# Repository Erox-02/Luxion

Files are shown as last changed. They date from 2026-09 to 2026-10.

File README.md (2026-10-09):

# Luxion

Luxion is a custom made drone made with rust unlike standard c++ drones .
It uses a custom pcb, ESP32-S3-WROOM-1U , MPU6500-IMU(breakout as it costs less than the bare), four motor drivers, and a 1S LiPo to power the drone. Also a remote with
same esp module, 2x joysticks connectin to the drone via esp-now .

## Function

It is a remote controlled drone made from absolutely nothing , with 8520 motors and 65mm props it can easily take off with 2+ thrust-mass ratio . It is ideal for mini quadcoptor with mountable sensors ,as it has a lot of gpio's left any sensor can be easily mounted if not too heavy .

## Why it exists

from when i saw the pluto x  , a programable drone with esp 12f and stm32 , i always wanted to make one myself but better and cheaper thts why luxion exists today. I used esp32-s3 instead of 2 mcu's , used esp-now instead of wifi and a lot but the best part i didnt rely on the pluto x's architecture at all .

## Design
---

### 3D Model

> **Notice: All the screws there are 3mm .** 

The recommended range by me is M5x3 mm 

heres a photo tagged:
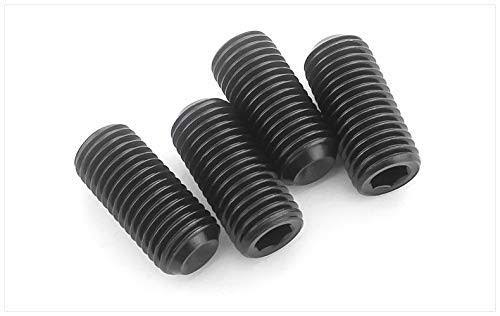
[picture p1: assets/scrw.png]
 

but for the pcb M1.2x3 mm is totally usable 

#### Drone

You can download the 3d model frm here :
[DOWNLOAD THE 3d MODEL](3d/lux.3mf)

also the  fcstd file is tagged here :

[FCSTD](3d/lux.FCStd)

some photos for the frame :

<table>
  <tr>
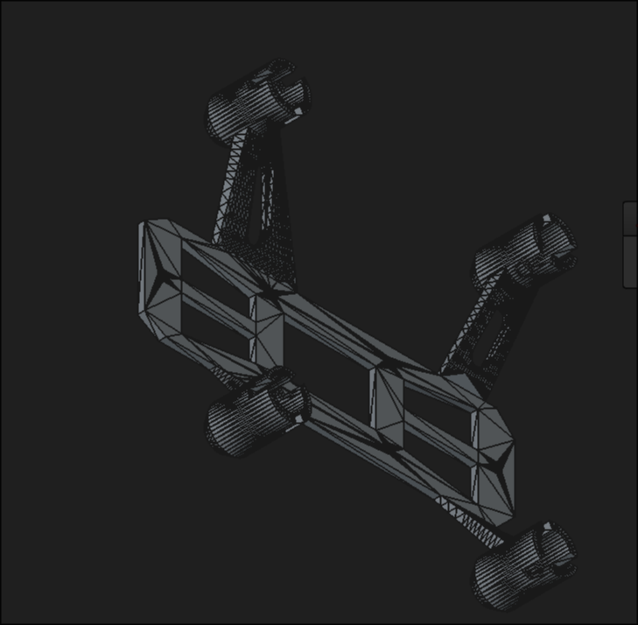
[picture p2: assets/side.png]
side view
    <td></td>
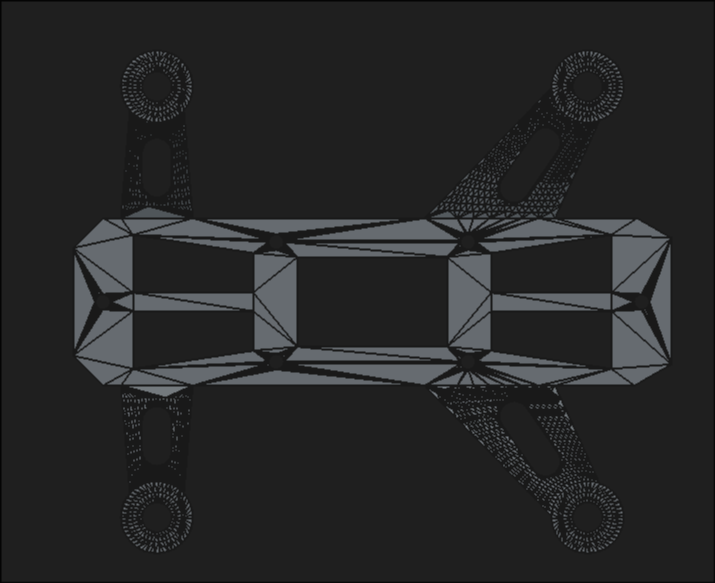
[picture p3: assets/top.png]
top view
    <td></td>
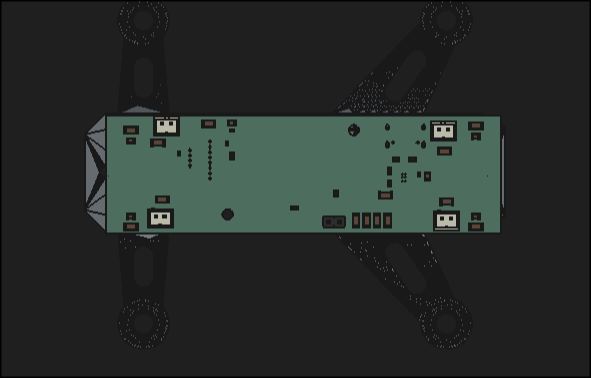
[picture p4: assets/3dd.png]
with pcb
    <td></td>
  </tr>
</table>

---

#### Remote

You can download the 3d model frm here :

[DOWNLOAD THE 3d MODEL](3d/remote-body.3mf)
[DOWNLOAD THE 3d MODEL](3d/remote-lid.3mf)

===

also the  fcstd file is tagged here :

[FCSTD](3d/remote.FCStd)

Some phots of the remote :

<table>
  <tr>
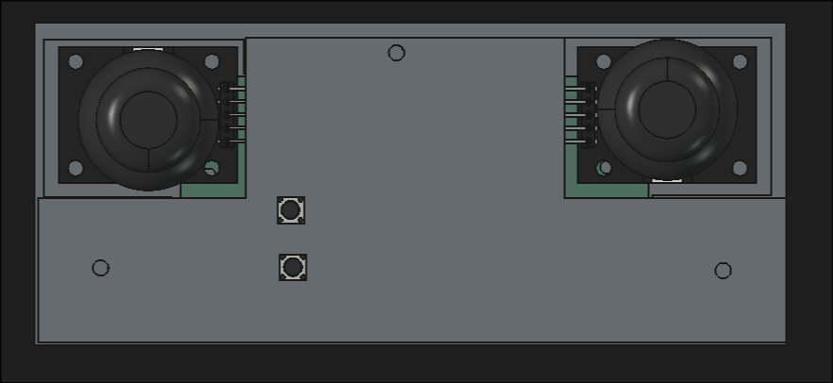
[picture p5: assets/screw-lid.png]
top
    <td></td>
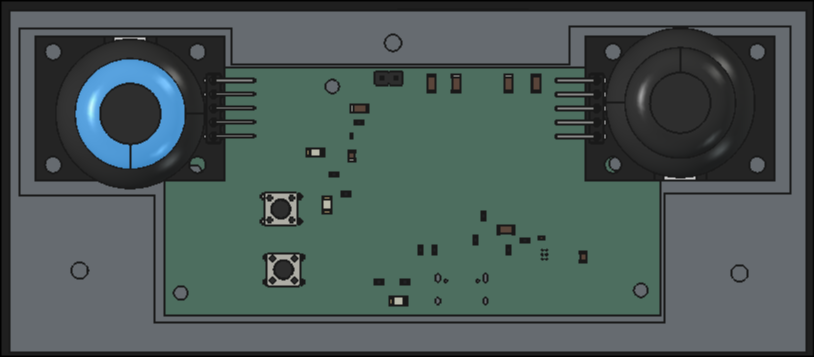
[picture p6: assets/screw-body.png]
case open
    <td></td>
  </tr>
</table>

---

### Schematic
---

#### drone

<table>
  <tr>
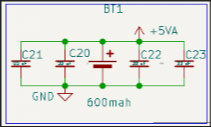
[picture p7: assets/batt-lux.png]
battery
    <td></td>
    <td>motor drivers</td>
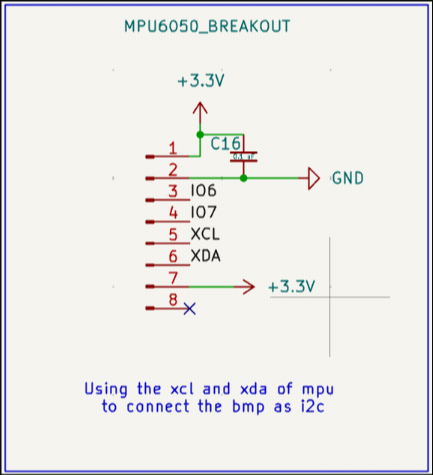
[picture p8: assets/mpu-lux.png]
mpu6050
    <td></td>
  </tr>
  <tr>
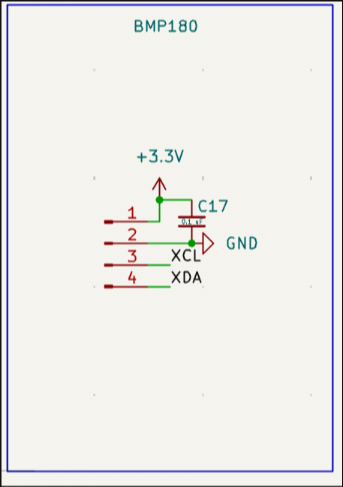
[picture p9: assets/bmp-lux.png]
barometer
    <td></td>
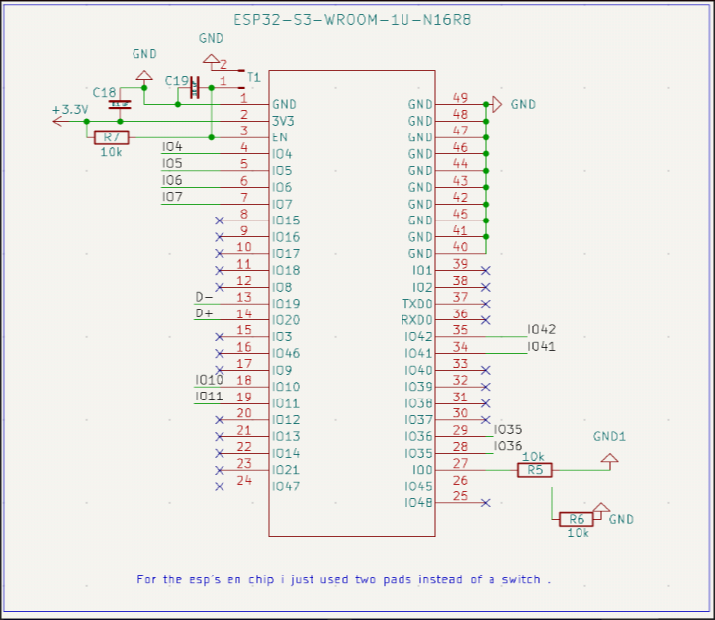
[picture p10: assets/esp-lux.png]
mcu(esp32-s3)
    <td></td>
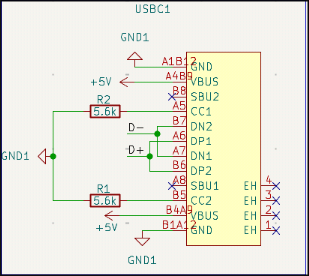
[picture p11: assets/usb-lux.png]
usb-c
    <td></td>
  </tr>
  <tr>
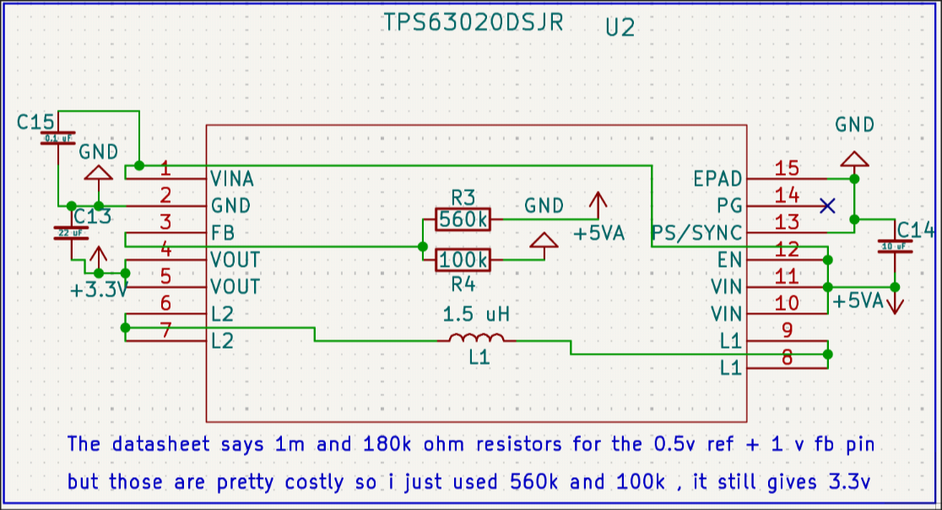
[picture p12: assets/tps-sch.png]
step up (tps63020)
    <td></td>
    <td>motors</td>
  </tr>
</table>

---

#### remote
---

<table>
  <tr>
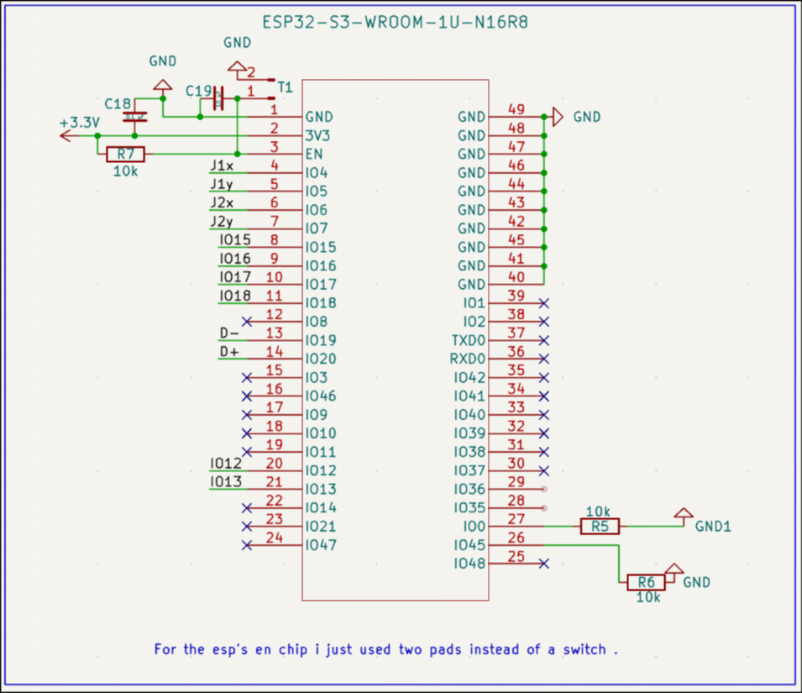
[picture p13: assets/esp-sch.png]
mcu
    <td></td>
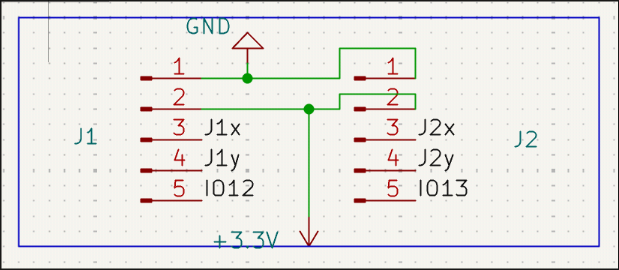
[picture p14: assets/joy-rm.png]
joystick
    <td></td>
  </tr>
  <tr>
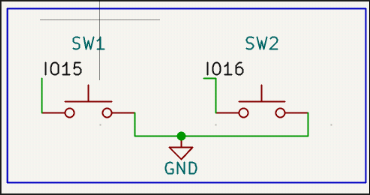
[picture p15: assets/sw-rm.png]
switchs
    <td></td>
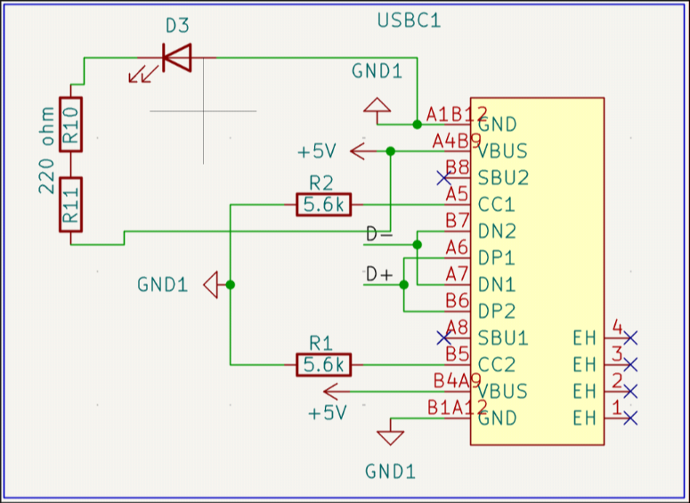
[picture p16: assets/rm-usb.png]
usb c
    <td></td>
  </tr>
</table>

### PCB

#### drone

Heres the pcb :

<table>
  <tr>
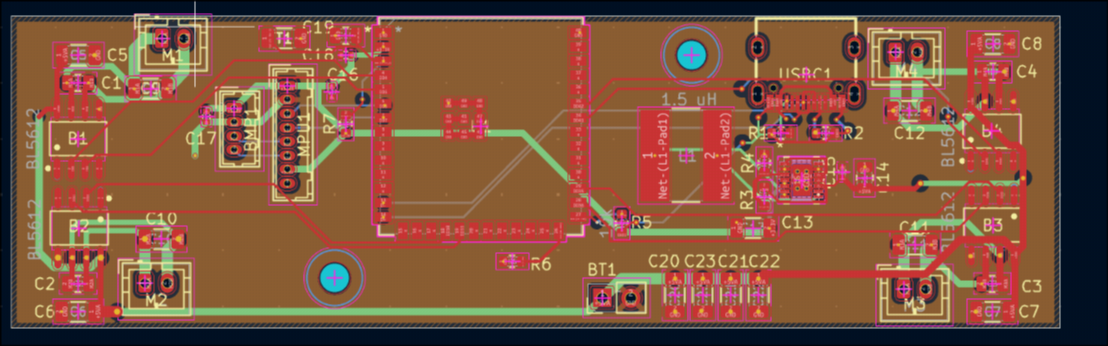
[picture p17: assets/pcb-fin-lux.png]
drone pcb
    <td></td>
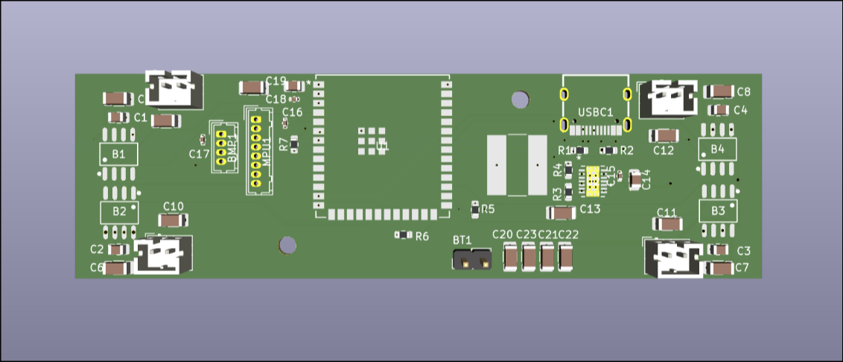
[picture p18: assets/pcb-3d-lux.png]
drone pcb 3d
    <td></td>
  </tr>
</table>

#### remote

Heres the pcb :

<table>
  <tr>
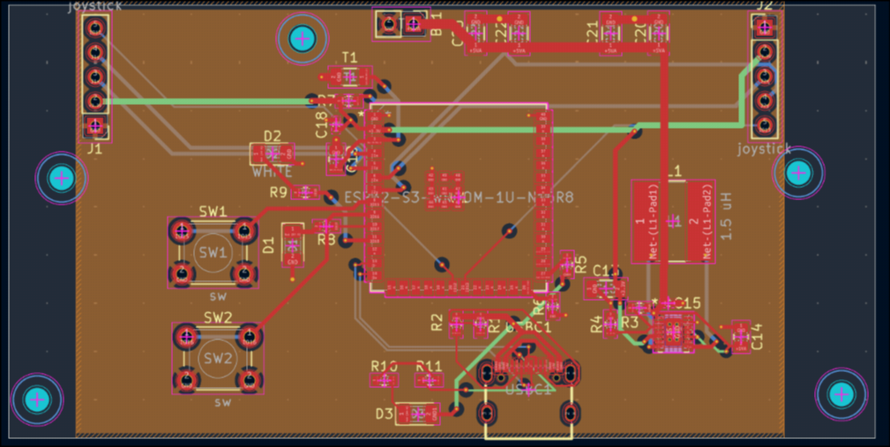
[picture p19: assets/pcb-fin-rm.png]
remote pcb
    <td></td>
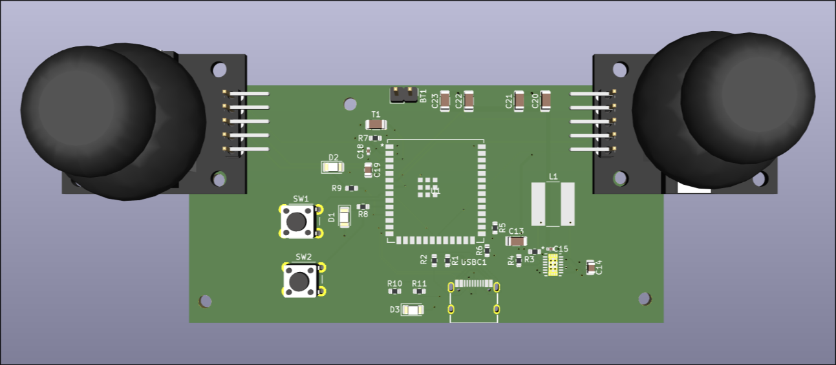
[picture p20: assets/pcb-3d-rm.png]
remote pcb 3d
    <td></td>
  </tr>
</table>

## Firmware

I have written likely most of the firmware already before getting approved or building the physical drone .

Current stack have :
```
[erox@archbtw luxion]$ tree src 
src
├── filter.rs
├── main.rs
├── motor.rs
├── mpu.rs          
└── pid.rs

1 directory, 5 files
```

the mpu.rs is a custom driver(really basic) for the mpu6050 , the filte* take mpu's data(gyro and acc) then converts tht into yaw roll and pitch , the moto* haved ldec and controlls the motors state , the pid is just pid controller nothing more , and the main.rs integrates them all and runs them when needed either in loop or once .

### Whats remainin?

- esp now impl
- build.rs
- proper pid vals and calibration

## How to assemble

Solder all the components from bom(except the antenna) on the pcb ,
also You might need to solder a jst socket according to your battery
(more detailed explanation after i do it myself first lol)

you can follow this hand drawn diagram(even orphy is better than me)
---
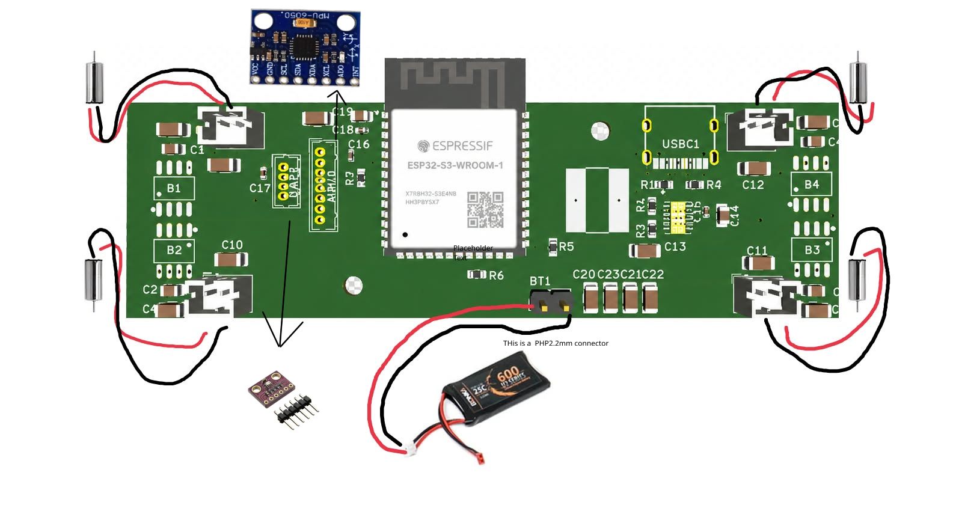
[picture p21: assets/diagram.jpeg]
diagram

---

## Credits

This project uses:

- KiCad
- Freecad for 3D renders
- A opensource frame from the link below

[link](https://www.thingiverse.com/thing:5013951)

> It was the reference for my frame i had to rebuild it .

## JLCPCB order

---
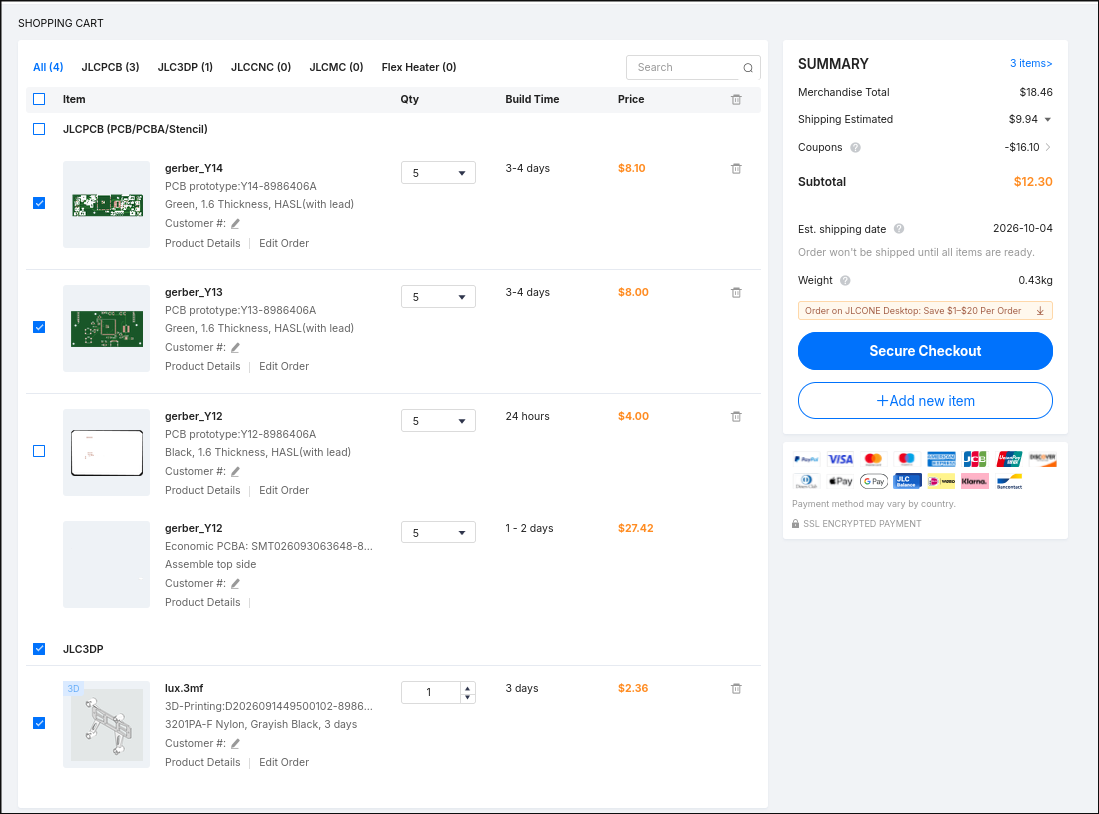
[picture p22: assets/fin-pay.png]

---

> the price might fluctuate over time

## BOM

| Part | Quantity | Unit Price (INR) | Unit Price (USD) | Total (INR) | Total (USD) | Link |
|---|---:|---:|---:|---:|---:|---|
| MPU-6050 3-Axis Accelerometer + Gyro | 1 | 151.00 | 1.59 | 151.00 | 1.59 | [Link](https://robu.in/product/mpu-6050-gyro-sensor-2-accelerometer/) |
| PS2 Joystick Module Breakout Sensor | 2 | 39.00 | 0.41 | 78.00 | 0.82 | [Link](https://robu.in/product/joystick-module-ps2-breakout-sensor/) |
| 8520 Magnetic Micro Coreless Motors – 2xCW + 2xCCW pack | 1 | 459.00 | 4.83 | 459.00 | 4.83 | [Link](https://robu.in/product/8520-magnetic-micro-coreless-motor-for-micro-quadcopters-2xcw-2xccw/) |
| 100kΩ 0603 resistor (MOQ) | 30 | 0.34 | 0.004 | 10.20 | 0.11 | [Link](https://robu.in/product/100k-ohm-1-4w-0603-surface-mount-chip-resistor-pack-of-100/) |
| 220Ω 0603 resistor (MOQ) | 30 | 0.34 | 0.004 | 10.20 | 0.11 | [Link](https://robu.in/product/220-ohm-chip-resistor-1-4w-0603-surface-mount-pack-of-100/) |
| 3V Active Electromagnetic Buzzer – pack of 5 | 1 | 21.00 | 0.22 | 21.00 | 0.22 | [Link](https://robu.in/product/3v-active-electromagnetic-buzzer-pack-of-5/) |
| 1206 Surface Mount LED White (MOQ) | 10 | 1.07 | 0.011 | 10.70 | 0.11 | [Link](https://robu.in/product/1206-surface-mount-led-white-50-pcs/) |
| 1206 Surface Mount LED Yellow (MOQ) | 25 | 0.40 | 0.004 | 10.00 | 0.11 | [Link](https://robu.in/product/1206-surface-mount-led-yellow-50pcs/) |
| BMP180 Digital Barometric Pressure Sensor Module | 1 | 33.00 | 0.35 | 33.00 | 0.35 | [Link](https://robu.in/product/bmp180-digital-barometric-pressure-sensor-module/) |
| LWC-2400-DIP-03 (V1.0) Dipole Antenna 2.4 GHz | 2 | 132.00 | 1.39 | 264.00 | 2.78 | [Link](https://robu.in/product/lwc-2400-dip-03-v1-0-dipole-antennas-2-4-ghz/) |
| Bonka 3.7V 600mAh 25C 1S LiPo | 1 | 499.00 | 5.25 | 499.00 | 5.25 | [Link](https://robu.in/product/bonka-3-7v-600mah-25c-1s-lithium-polymer-battery-pack/) |
| 22µF 16V 1206 X5R capacitor (MOQ) | 28 | 0.36 | 0.004 | 10.08 | 0.11 | [Link](https://robu.in/product/1206x226k160ct-samsung-smd-multilayer-ceramic-capacitor-22-%c2%b5f-16-v-1206-3216-metric-%c2%b1-10-x5r/) |
| 100nF 0402 X7R capacitor (MOQ) | 100 | 0.10 | 0.001 | 10.00 | 0.11 | [Link](https://robu.in/product/im02b104k250nb-fh-smd-multilayer-ceramic-capacitor-0-1-%c2%b5f100-nf-25-v-0402-1005-metric-%c2%b1-10-x7r-cl/) |
| 10kΩ 0603 resistor (MOQ) | 15 | 0.68 | 0.007 | 10.20 | 0.11 | [Link](https://robu.in/product/ac0603fr-0710kl-yageo-res-thick-film-0603-10k-ohm-1-0-1w1-10w-%c2%b1100ppm-c-pad-smd-t-r-automotive-aec-q200/) |
| ESP32-S3-WROOM-1U-N16R8 | 2 | 469.00 | 4.94 | 938.00 | 9.87 | [Link](https://robu.in/product/espressif-esp32-s3-wroom-1u-n16r8-module/) |
| 10µF 10V 0805 X5R capacitor (MOQ) | 22 | 0.47 | 0.005 | 10.34 | 0.11 | [Link](https://robu.in/product/cs2012x5r106m100nre-samwha-10v-x5r-0805-multilayer-ceramic-capacitors-mlcc-smd-smt-rohs/) |
| SRN8040-1R5Y 1.5µH 7A inductor | 1 | 23.00 | 0.24 | 23.00 | 0.24 | [Link](https://robu.in/product/srn8040-1r5y-bourns-srn8040-1r5y-power-inductor-smd-1-5-%c2%b5h-7-a-shielded-8-2-a-srn8040-series/) |
| BL5612-BL H-Bridge Motor Driver IC | 4 | 41.00 | 0.43 | 164.00 | 1.73 | [Link](https://robu.in/product/bl5612-blshanghai-belling-h-bridge-motor-driver-ic-1-5a-sop-8/) |
| 560kΩ 0603 resistor (MOQ) | 28 | 0.36 | 0.004 | 10.08 | 0.11 | [Link](https://robu.in/product/erjp03j564v-panasonic-200mw-thick-film-resistors-%c2%b15-%c2%b1200ppm-%e2%84%83-560k%cf%89-0603-chip-resistor-surface-mount-rohs/) |
| 5.6kΩ 0603 resistor (MOQ) | 28 | 0.37 | 0.004 | 10.36 | 0.11 | [Link](https://robu.in/product/erj3geyj562v-panasonic-100mw-thick-film-resistors-%c2%b15-%c2%b1200ppm-%e2%84%83-5-6k%cf%89-0603-chip-resistor-surface-mount-rohs/) |
| TYPE-C-31-M-12 Hroparts 5A 1 16P Female Type-C SMD USB Connector | 2 | 26.00 | 0.27 | 52.00 | 0.55 | [Link](https://robu.in/product/type-c-31-m-12-hroparts-5a-1-16p-female-type-c-smd-usb-connectors-rohs/) |
| JST 2P Male + Female Terminal Connection Socket | 1 | 30.00 | 0.32 | 30.00 | 0.32 | [Link](https://robu.in/product/jst-2p-malefemale-terminal-connection-socket/) |
| TPS63020DSJR | 2 | 178.00 | 1.87 | 356.00 | 3.75 | [Link](https://robu.in/product/tps63020dsjr-texas-instruments-boost-type-adjustable-1-2v5-5v-1-8v5-5v-vson-14-ep3x4-dc-dc-converters-rohs/) |
| **Drone PCB** | 1 | 769.50 | **8.10** | 769.50 | **8.10** | — |
| **Remote PCB** | 1 | 760.00 | **8.00** | 760.00 | **8.00** | — |
| **Drone Frame** | 1 | 224.20 | **2.36** | 224.20 | **2.36** | — |
| **TOTAL** | | | | **4,923.86** | **51.83** | |

> i used 95inr = 1$ , also the prices gonna change soon .

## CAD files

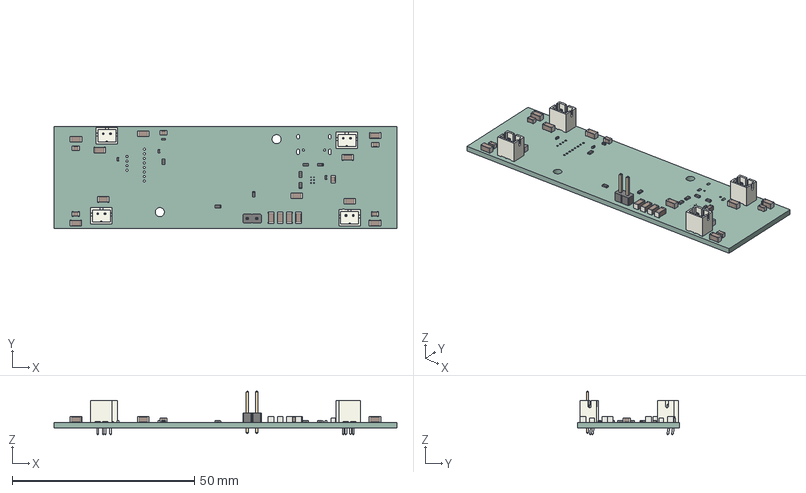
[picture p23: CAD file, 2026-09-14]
3d/drone/drone_pcb.step
94.0 x 28.0 x 11.9 mm
C_0402_1005Metric x 4
JST_B2B_PH_K x 4
C_1206_3216Metric x 14
R_0603_1608Metric x 7
C_0805_2012Metric x 6
PinHeader_1x02_P254mm_Vertical
lux-unsaved-export-ZjX12o_PCB

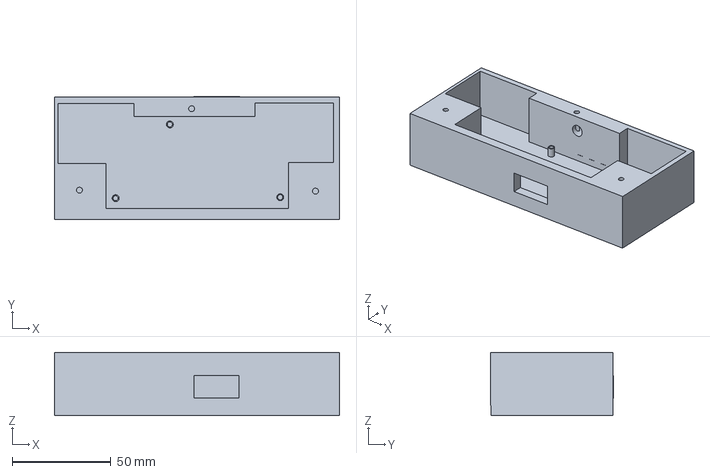
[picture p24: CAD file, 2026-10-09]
3d/remote/remote-Body.3mf
144.6 x 62.2 x 32.0 mm

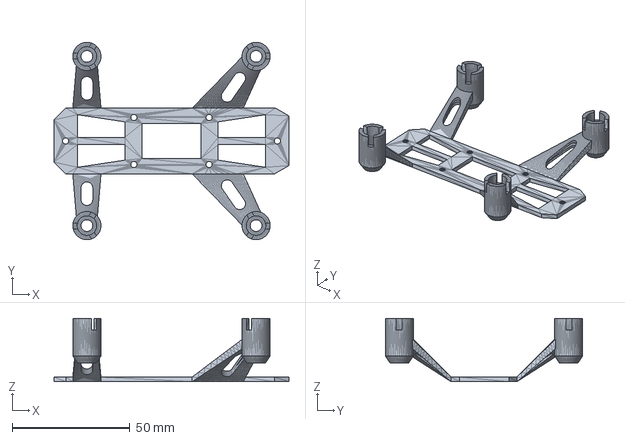
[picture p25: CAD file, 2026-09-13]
3d/drone/lux.FCStd
100.0 x 84.0 x 27.0 mm

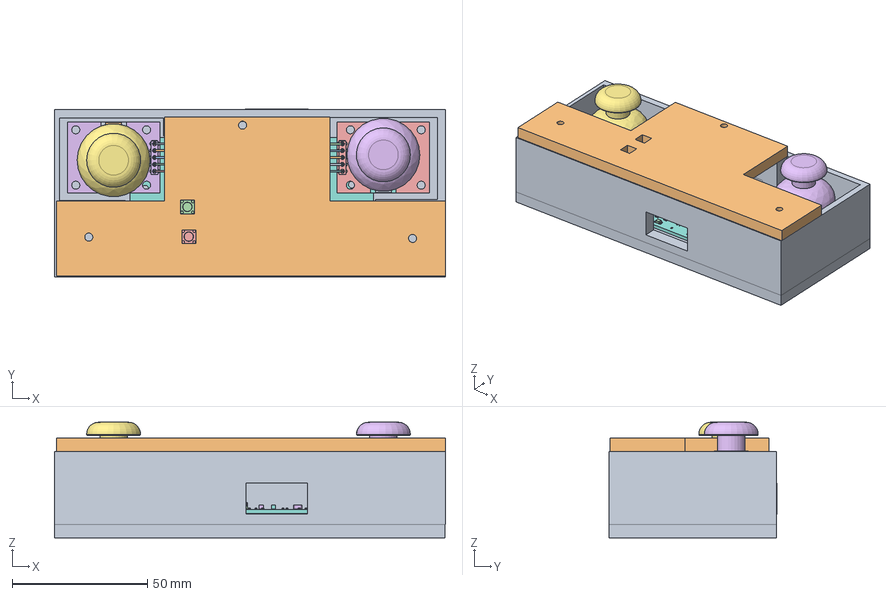
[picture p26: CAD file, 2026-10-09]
3d/remote/remote.FCStd
144.7 x 62.2 x 42.8 mm
R_0603_1608Metric
LED_1206_3216Metric
R_0603_1608Metric002
LED_1206_3216Metric002
PinHeader_1x05_P254mm_Vertical
joy_stick v2
joy_stick v001
joy_stick v002
joy_stick v003
joy_stick v004
joy_stick v005
joy_stick v006
joy_stick v007
joy_stick v008
joy_stick v009
joy_stick v010
joy_stick v011
joy_stick v012
joy_stick v013
joy_stick v014
joy_stick v015
joy_stick v016
joy_stick v017
joy_stick v018
joy_stick v019
joy_stick v020
joy_stick v021
joy_stick v022
joy_stick v023
joy_stick v024
R_0603_1608Metric004
C_0402_1005Metric
C_1206_3216Metric
R_0603_1608Metric006
C_0805_2012Metric
SW_PUSH_6mm_h5mm
SW_PUSH_6mm_h5mm001
PinHeader_1x02_P254mm_Vertical
R_0603_1608Metric008
C_1206_3216Metric002
C_1206_3216Metric004
R_0603_1608Metric010
C_0805_2012Metric002
PinHeader_1x05_P254mm_Vertical001
joy_stick v026
joy_stick v027
joy_stick v028
joy_stick v029
joy_stick v030
joy_stick v031
joy_stick v032
joy_stick v033
joy_stick v034
joy_stick v035
joy_stick v036
joy_stick v037
joy_stick v038
joy_stick v039
joy_stick v040
joy_stick v041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

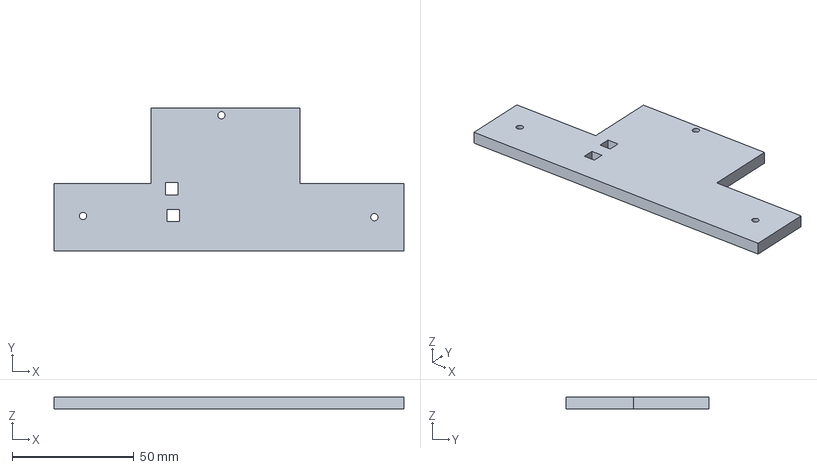
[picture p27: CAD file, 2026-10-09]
3d/remote/remote-lid.3mf
143.9 x 58.7 x 5.00 mm

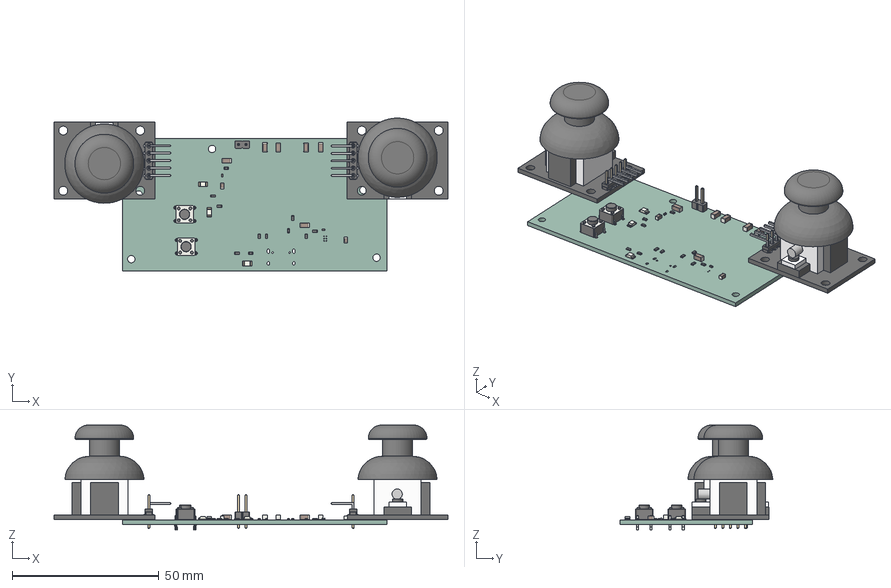
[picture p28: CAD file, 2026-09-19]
3d/remote/rm_pcb.step
134.1 x 52.0 x 35.7 mm
R_0603_1608Metric x 11
LED_1206_3216Metric x 3
PinHeader_1x05_P254mm_Vertical x 2
joy_stick v2 x 2
C_0402_1005Metric x 2
C_1206_3216Metric x 6
C_0805_2012Metric x 2
SW_PUSH_6mm_h5mm x 2
PinHeader_1x02_P254mm_Vertical
remote_PCB

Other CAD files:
3d/drone/lux.3mf

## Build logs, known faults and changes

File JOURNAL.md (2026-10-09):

---
title: "Luxion"
author: "Dipanjan Dutta"
description: "A tiny esp32 drone but in rust"
created_at: "2026-09-04"
---

# Sept 4 : Started the schematic

Today i started the first part of lux , i simply designed the initial base(i mean schematic only) of pcb now gonna polish tht . Heres an img :
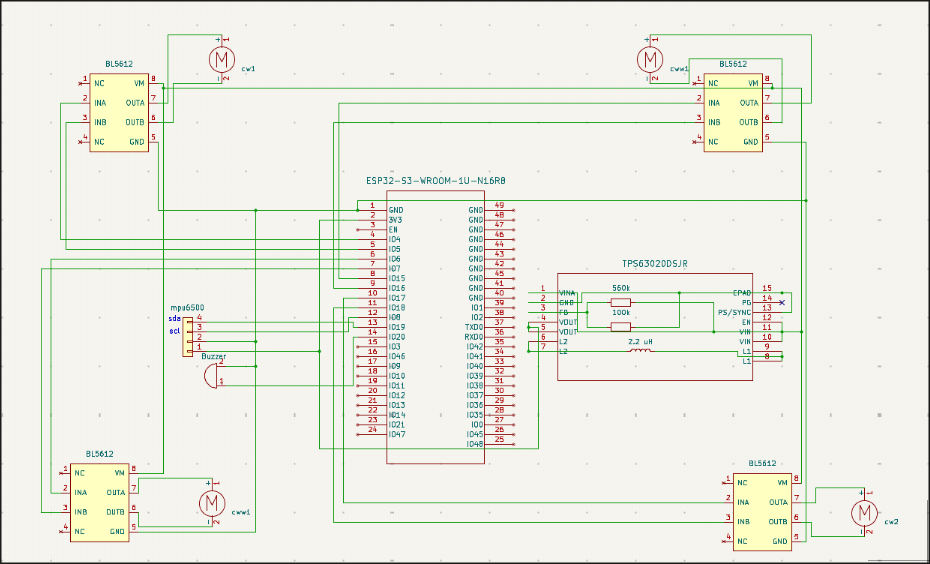
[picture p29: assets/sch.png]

So to be frank it took me hours to make the decisions for the h bridge driver , the buck converter and both of them not out of stock everywhere
, i chose bl5612 for the h bridge driver , looks good enough but for the buck , i chosed ams1117 first then came to know its really inefficient and a 1s battery cant reliably suppy for it ,so i went to TPS63020DSJR  but soon i came to realize why it wasnt a good choice for me . THe wiring of it is really complex thts all still i somehow did it , now the next for tomorrow , i need to make the rails for ttl and start the pcb maybe? Also today i connected the mpu6500 ,it might look in complete but i intend to solder the breakout directly on my pcb(ah cant find bare cheaper than the breakout) so only 4 pins(gnd vcc scl and sda) are good enough no need for more hassle .

**Total time spent: 4 hours**

# Sept 5 : 

I already have the probs i need to solve but i made a new decision , i will just wire the d+ and d- on io20 and 19 , so no cp2102 as the esp already have the required pins , why waste money? 

But now i have mapped d+ and d- to gpio20 and 19 so now i need to remount the buzzer also the mpu , i think if i am rewiring , why not spi thts cleaner than i2c for a flight controller , so now i need conn_01x10 instead . Uf finally done now i need to add some good looking caps and then done the schematic , wait i have already spent 3hrs and basically did nothing but read datasheets and clculated the values for caps and wired some small things , ah! .

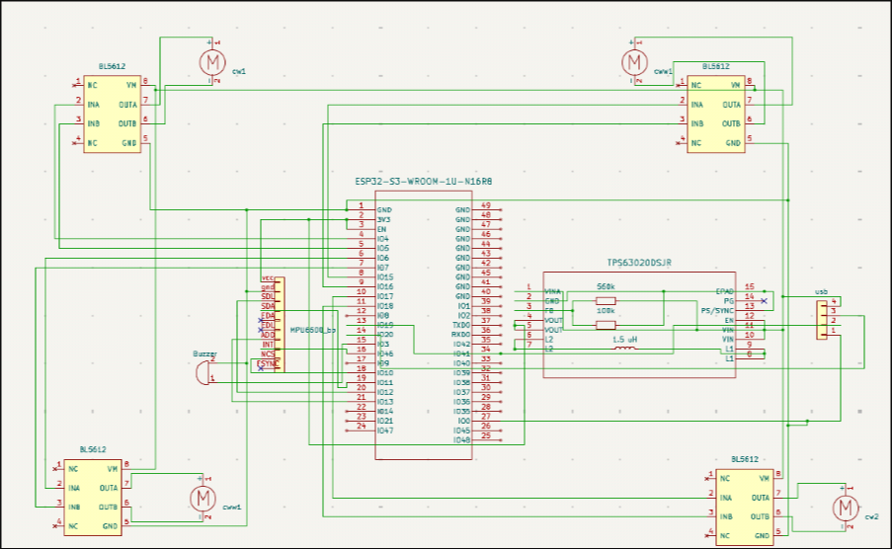
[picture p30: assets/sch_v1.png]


Now when i went to robu for the caps , i saw those cheap as hell but then comes 10rs is min for a single comp , i really need to order whole 25 caps just to fullfill their condition of 10rs minimum , anyways bulk costs way cheaper , when i tried to find alts , i saw each costing 3rs while on bulk 
the same comp(from diff company) costs 0.40rs each. For the first time i am ordering more things to save money lol .

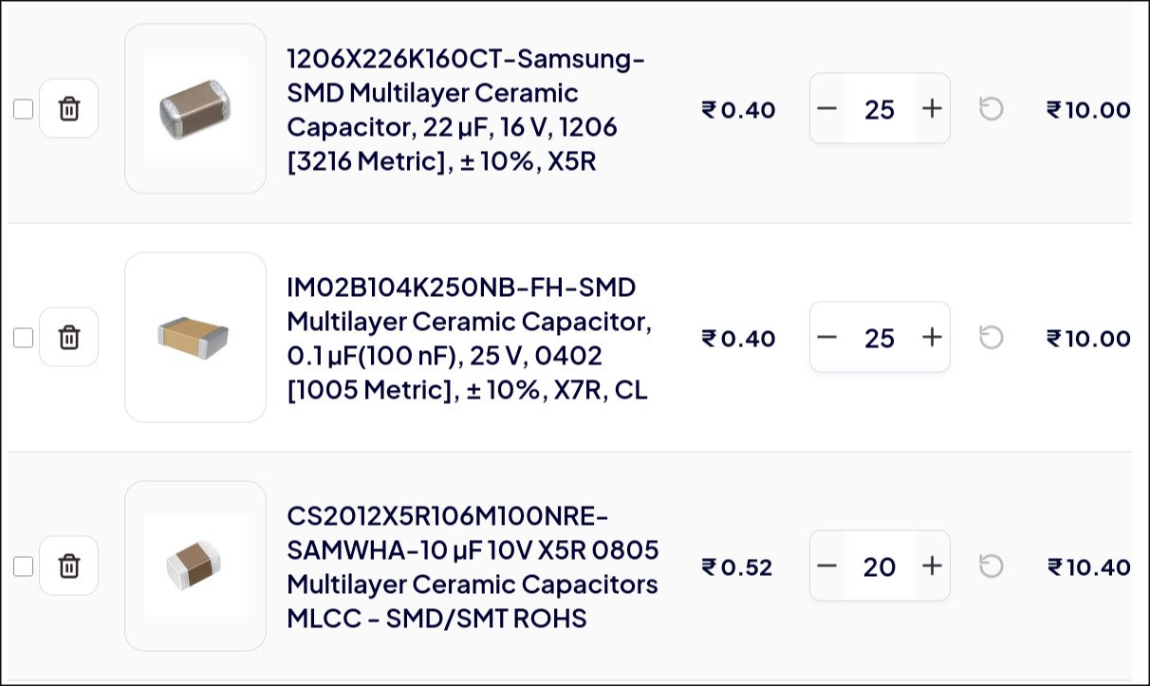
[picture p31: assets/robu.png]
robu


Finally done the caps arc Imma gonna die if i sill continue .

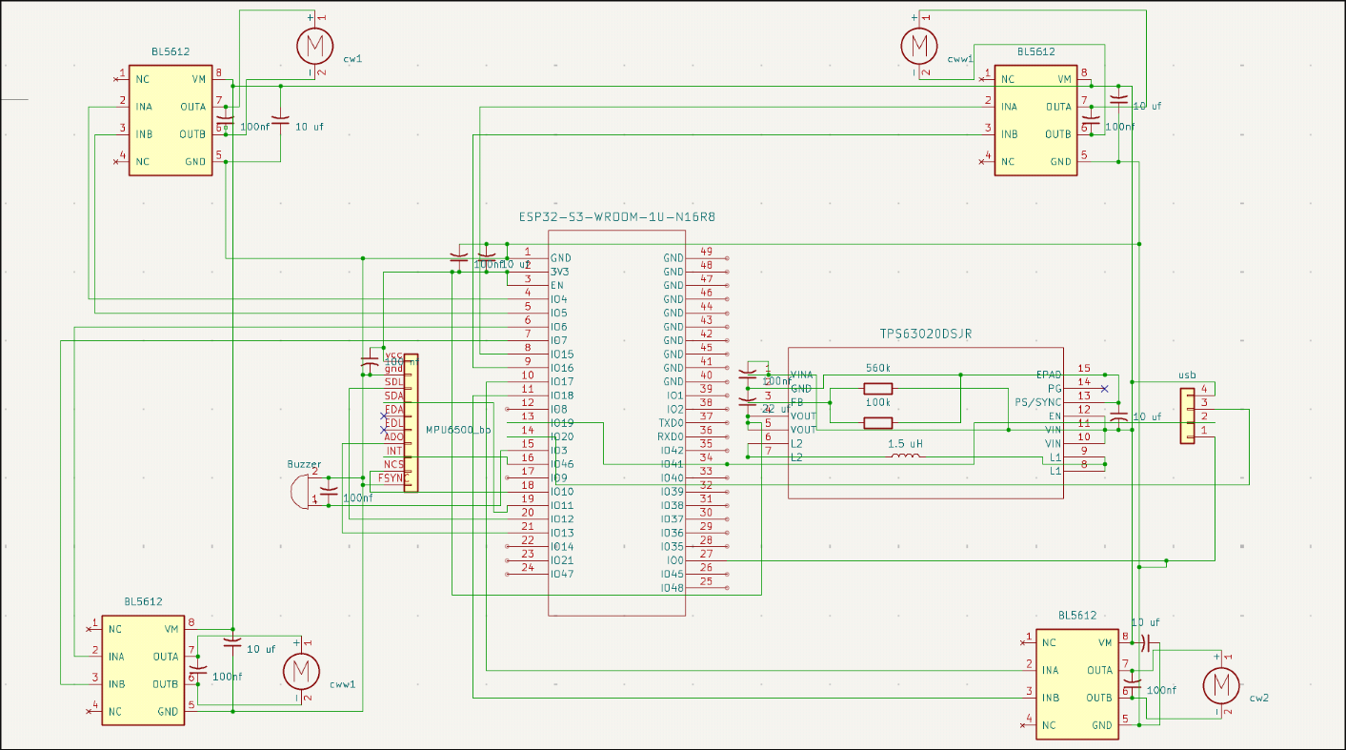
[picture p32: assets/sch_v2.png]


**Total time spent: 6 hours**

# Sept 6 : Footprint + pcb 

At firsted i started off with the usb connection , it might have looked finished but the old connection wd have caused the esp to struck in bootloader always so i did a easy trick diode between io0 and gnd done .

diode

Next the battery the one in my cart is a bonka 600mah 25c 1s lipo , and it have jst output but i cant get the exact size of the connecter , so i am just gonna leave the pcb with a conn_01x02 for the battery lol .

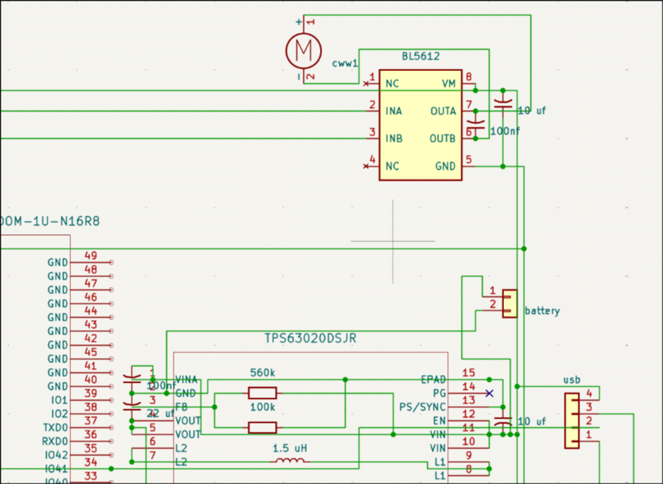
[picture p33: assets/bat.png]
battery


next if footprints : it took me literal an hour to find the exact footprints , it was hell , metric vs normal size of smd . As i was doin it for the first time , i sucked even more still somehow i pulled it off . And for the sod diode section it was too confusing .

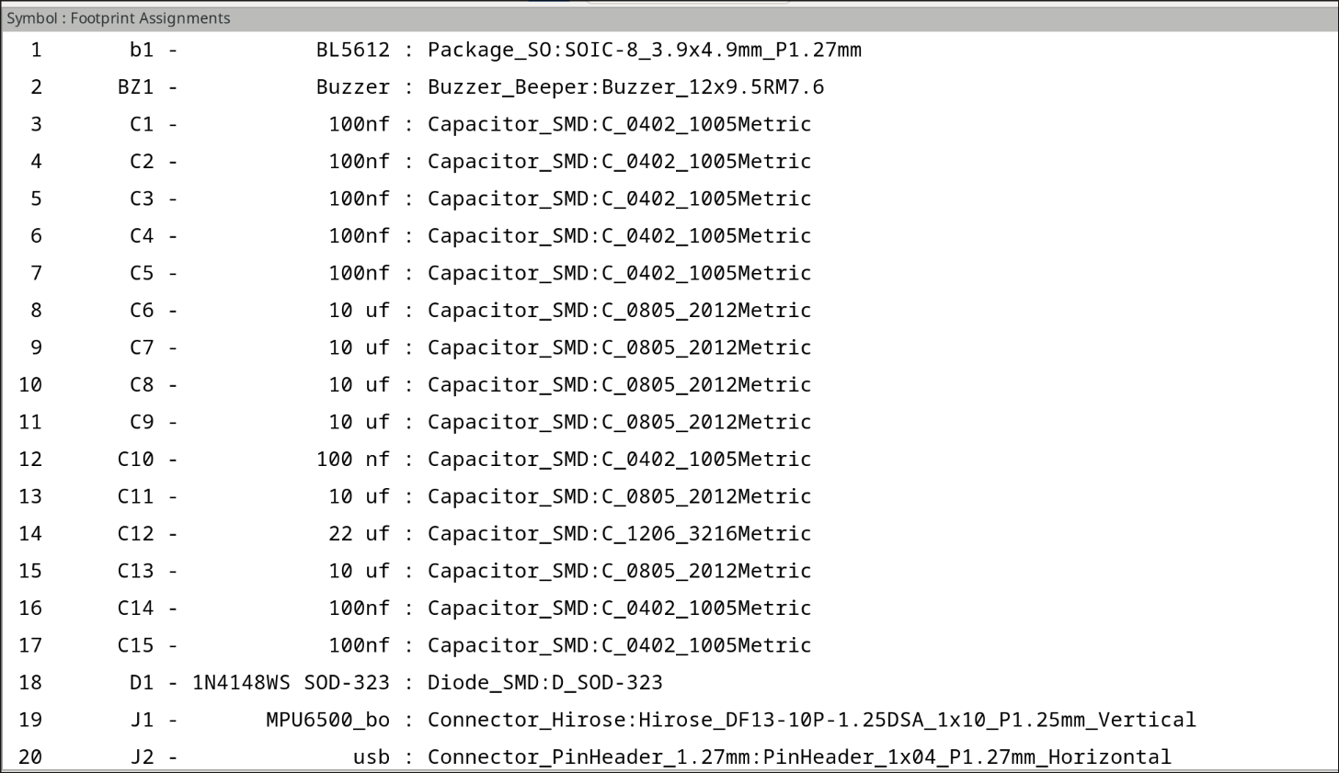
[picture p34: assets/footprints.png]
footprints


Now after tht i went to the pcb , and i came to know i only have 90x26mm space for the pcb . I tried to route and saw my mpu isnt connected to anything just because i changed the pin names from the original footprint , ah! .  Now i have 2 options either to go with the old pin 1-10 or make my own footprint for the mpu , quite a hard decision ! i took the easy one and reverted .

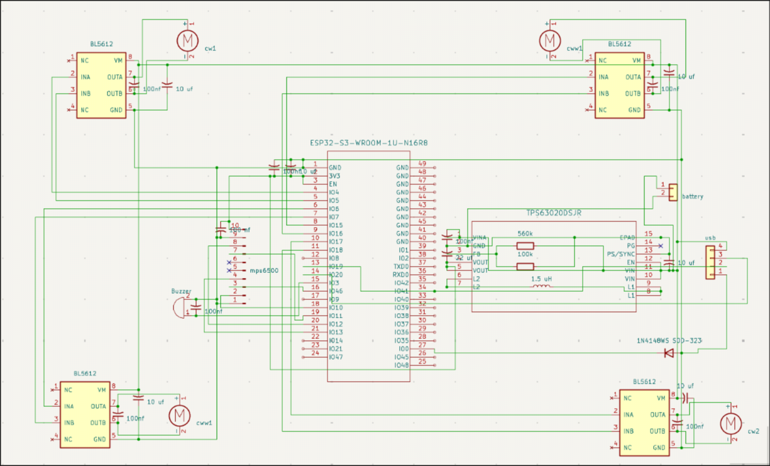
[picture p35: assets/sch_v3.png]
sch_last


now imma gonna do the pcb but before tht i have the frames size

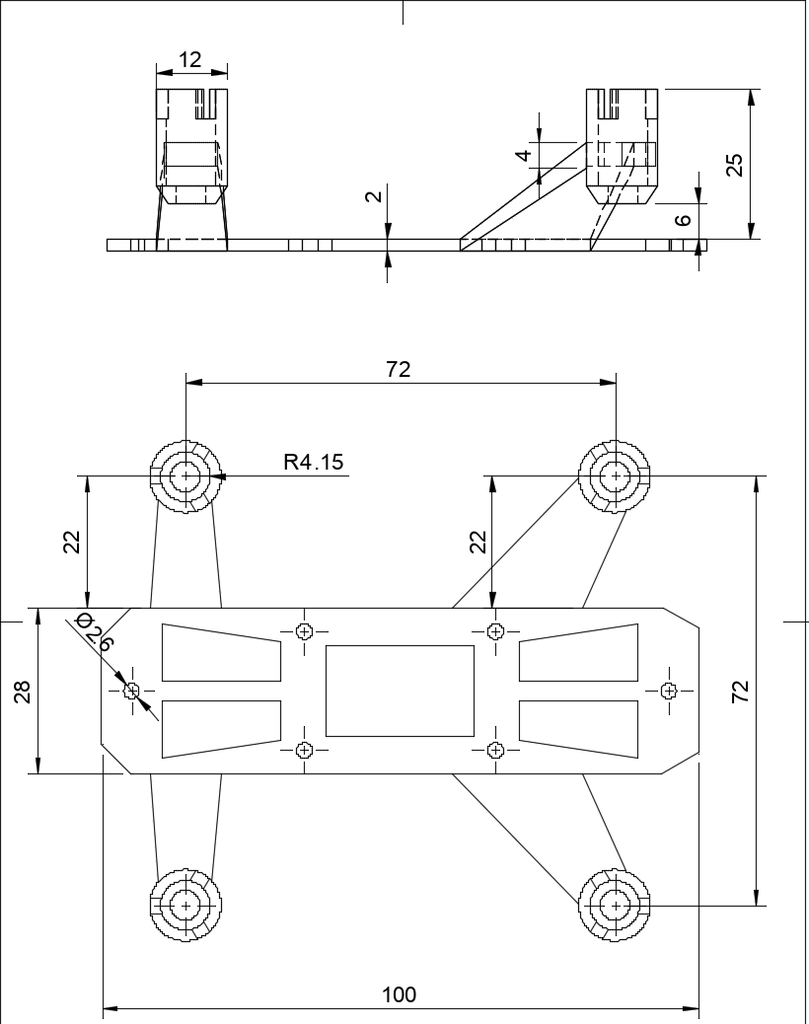
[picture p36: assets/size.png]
frame


i have measured i need 91x26mm^2 pcb tht will do the work probably. Now the main work routing the pcb . 
Why it looks this messy !!

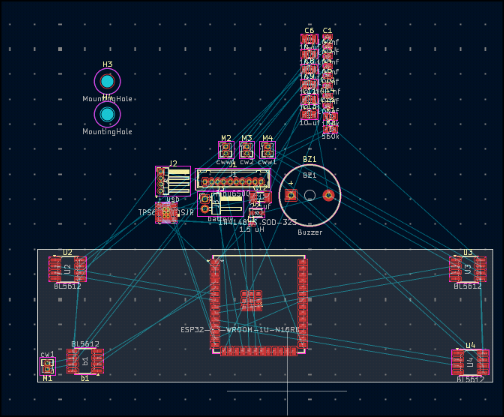
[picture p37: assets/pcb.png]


Actually i chosed the wrong footprint for the inductor too :x why it only happens with me ahhhhhhhhhhhhhhhhhhh. Ok i upgraded the footpring bt now it look like really big.

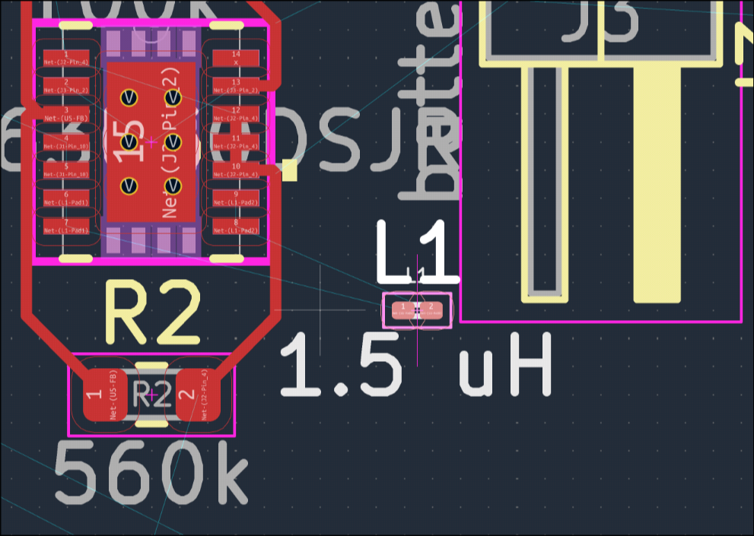
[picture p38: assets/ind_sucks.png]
inductor_smaller_footprint


i literally tried to wire those every thing in just 2 layers its toooo hard for me ah!

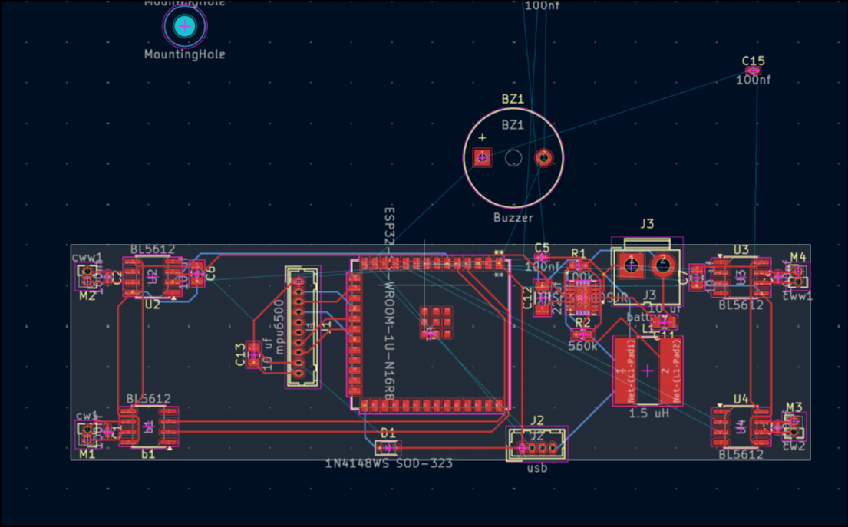
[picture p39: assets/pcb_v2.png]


lol I HAD TOO MANY ERRORS IN THE SCHEMATIC NOW NEED TO REFACTOR THE SCHEMATIC FIRST aAHHHHHHHHHHHHHHHHHHHHHHHHHHHHHHHHHHHHHHHHHHH.Its already 6hrs ahh .

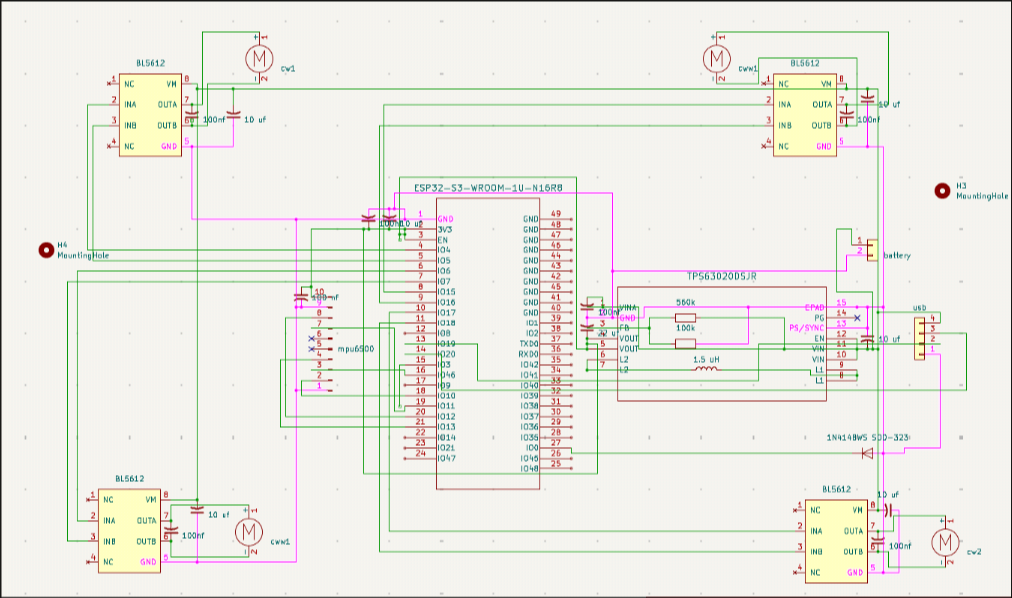
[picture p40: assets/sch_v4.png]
sch_final


finally this time i examined it carefully before goin to pcb , now lets do the pcb shit again .
Ok this time i place the motor positions with a scale , i mean i measured the motors position wrt to the frame and placed the comps now need to wire .

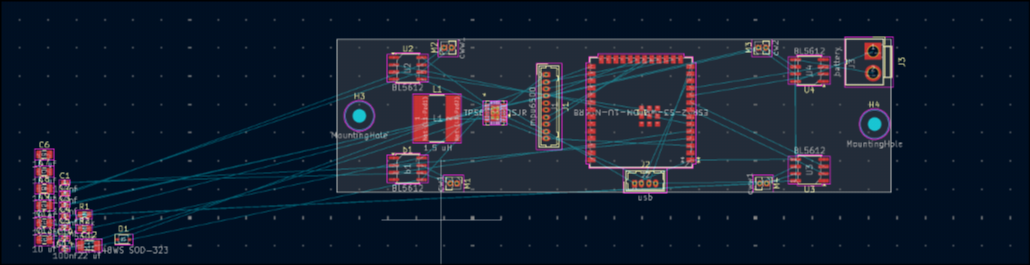
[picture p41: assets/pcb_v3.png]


Ahh again after another hour i kinda did the placement , take a look here 

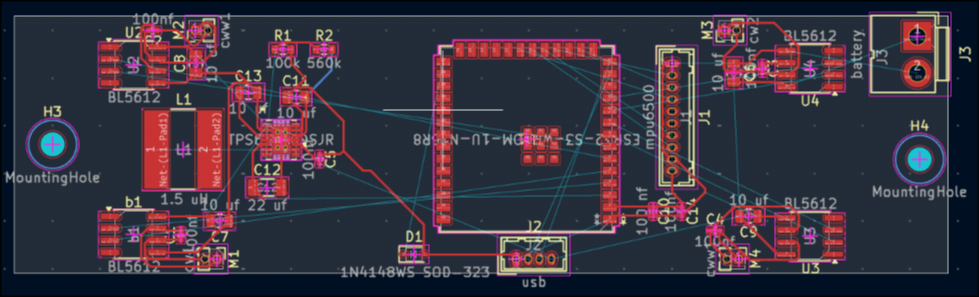
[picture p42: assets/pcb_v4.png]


Finally done i am crying , wait i didnt run drc .

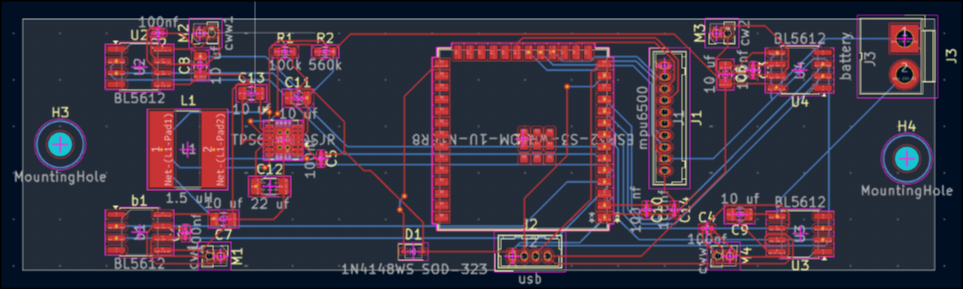
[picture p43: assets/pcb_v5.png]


**Total time spent: 8 hours**

# Sept 6 ptb :  Pcb polishing

DRC says i have errors but thts mostly trash as it says my tps63022's footprint has lower sized hole than the min , ahh my eyes are on fire ,i need to sleep still imma gonna fix it first .

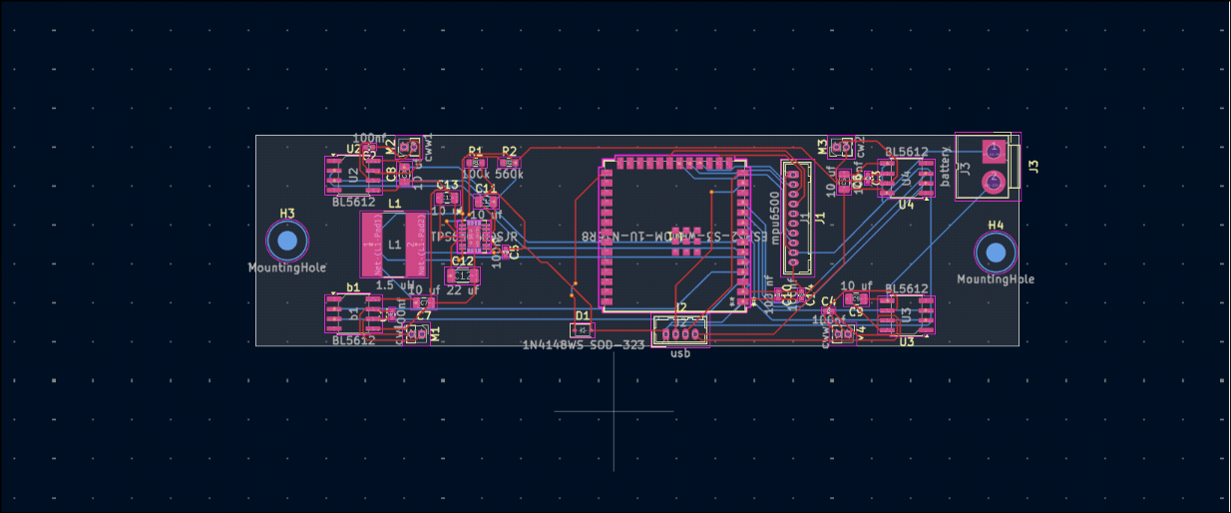
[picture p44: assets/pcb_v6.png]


looks like fixed and now i have a new job which is to add the drone's frame and pcb both in freecad and then check . 
It had a lil screw fitting issue i fixed tht but forgot to sc ah ! 

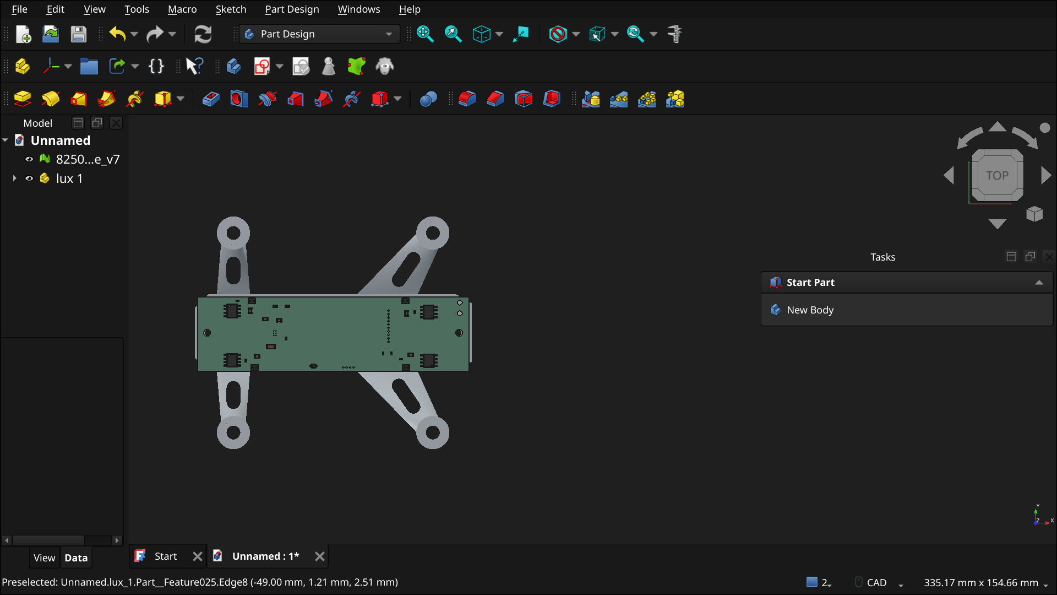
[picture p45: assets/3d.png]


This time i cut the pcb a lil to make it favorable with the 3d frame and this is the final result 

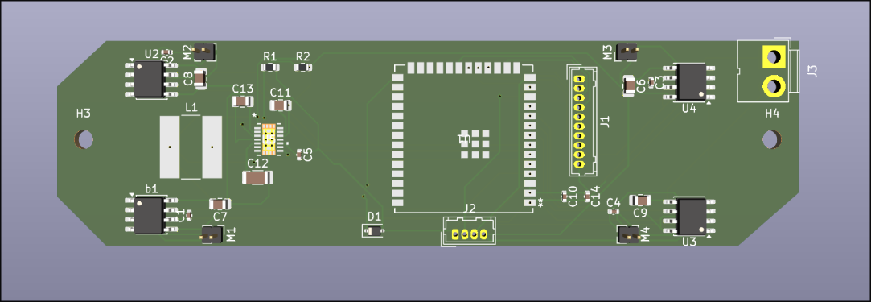
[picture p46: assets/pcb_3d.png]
coool


look like this is all i can do for today . Also looks like the designing part is complete ok then heres the final look: 

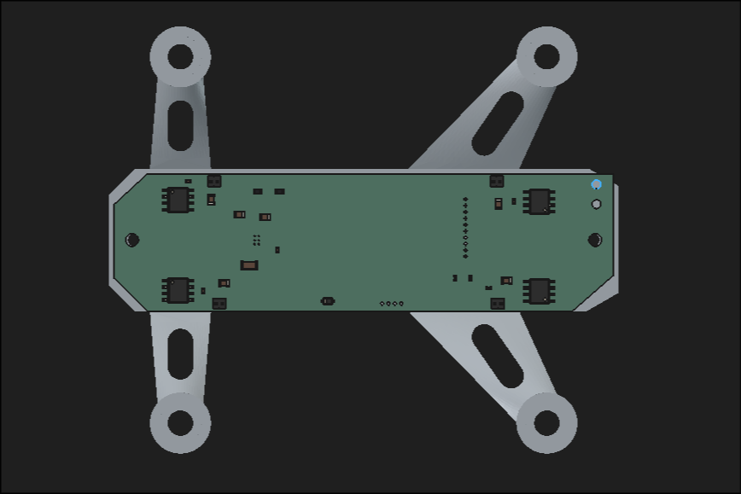
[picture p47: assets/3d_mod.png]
Final


**Total time spent: 2 hours**

# Sept 7 : cost estimation + readme fix

Today i didnt do much things just estimated the cost of pcb manufacturing and 3d printing i tried diff platforms like robu and jlcpcb also lion circuits but for pcb and 3d both jlcpcb makes it cheaper so why not , also with a 10$ coupon the shipping is free .

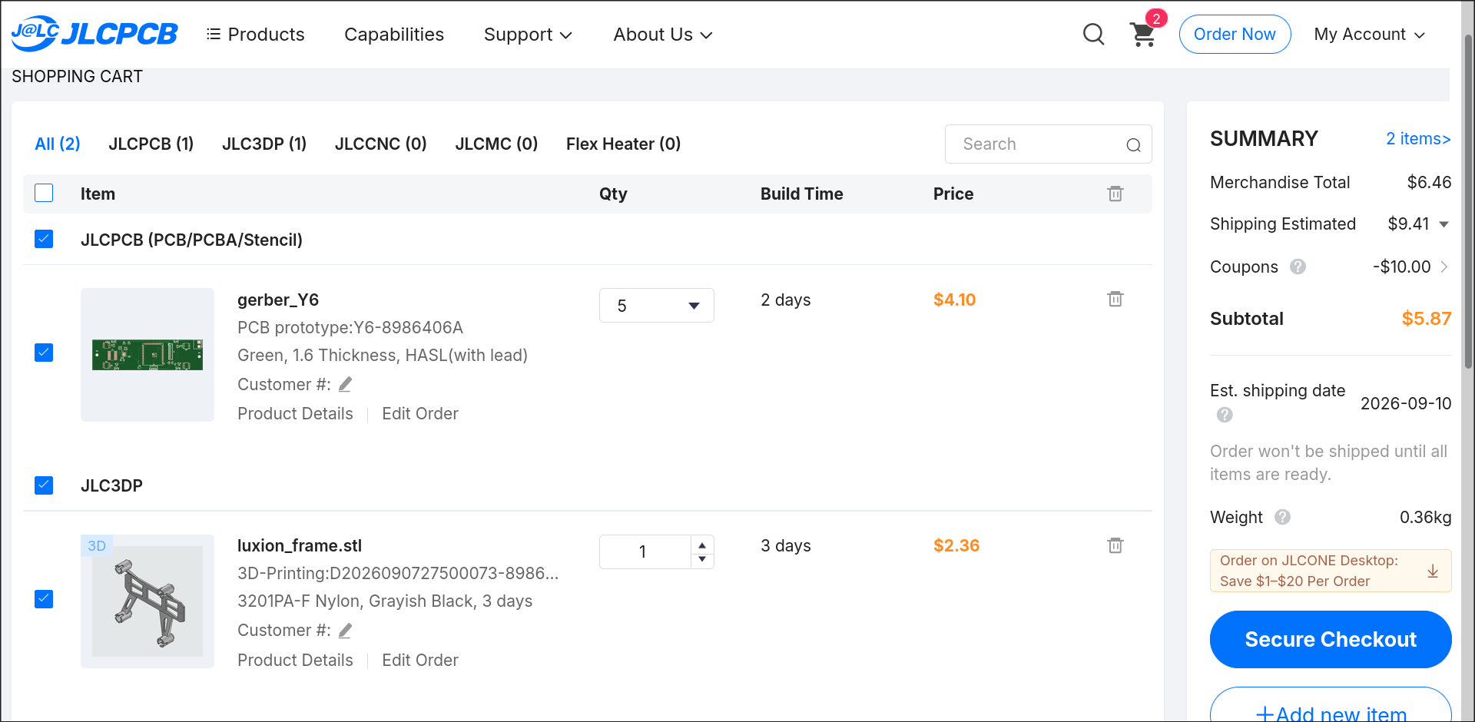
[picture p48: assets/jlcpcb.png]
pcb order


After that i tried a lot to find robu coupons too but i was unable to find so i basically gave up and went to readme , patched and thts all 

**Total time spent: 2 hours**

# Sept 8 : Wiring added to readme + bug found

today my work is minimal as i have a small exam , i just added the wiring portion to readme and found a bug ,
after reading the esp datasheet i came to know there is a strapping problem for gpio46 in my gerber ,
i mean when download mode with the usb , i need to pull tht down .

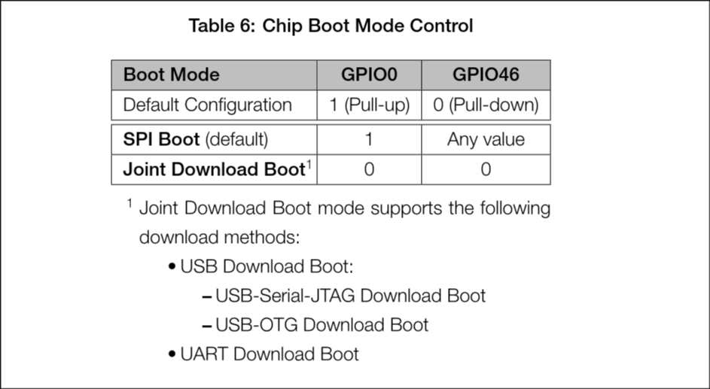
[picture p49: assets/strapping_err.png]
strapping ladout


**Total time spent: 1 hours**

# Sept 9 : Writing the Firmware 

Today imma gonna write the firmware maybe minimal ai but mostly me and my no_std rust ^w^

Bruh why the hell did i place m1 and m4 as cw instead of m1 and m3 i am definately goin to forget tht .
Ok wrote the init section of the main.rs now loop{} is remaining so i need to write the others first like mpu , pid *
it already took me 1 hrs idk how but it is kinda complex in no_std . 
Ok i wrote the motor.rs too its easy , i think the hard one will be the integrating these all . 

Now i will let deepseek help me with the pid , its not like i cant do tht myself but i dont wanna :C,
done , its easy , deepseek explained how the ki kd kp work in this case and the logic is good enough but lol i cant examine it until
i dont get lux approved and build the drone's physical body . Still lets mod the  pid for my needs ..

so pid.rs done too , next is filter.rs:

ok ik this filter was supposed to be a normal part but it isnt at all i need to either take a old reference code or let deepseek cook , ahh what am i gonna do?

i just took an old reference , modded it as it as i want and then asked gpt to explain the logic and equtions now its done or atleast i think so its done .
Its kinda easier than i thought we are just converting the a/gx , a/gy ,a/gx to angular degree thts all , using the del time thts all easypeasy. Also idh a magnetometer thts why i am doin acc + gyro to measure the down direction and if the drone is tilted and with that i am balancing the drift , it is the frankest explanation i have ever given. Btw initially i had a int vs fp bug in the struct of ComFil but i spotted tht even before commit , as expected i use arch btw .

ok now whts remainin? oh the mpu lemme do tht too ,

on mpu its kinda like i am writting the mpu driver myself instead of using the standard mpu6500 library blah blah blah as i am on no_std rust . Its not hard just you need to find the exact resisters and need to make the logic to cleanly read the WHO_Am_I res and test if it is the right one and then read sensor data's from the output resister easy right ?
done the mpu too , now i am in a pretty good position .
WAH i made THE BIGGEST MISTAKE IN MY WHOLE LIFE

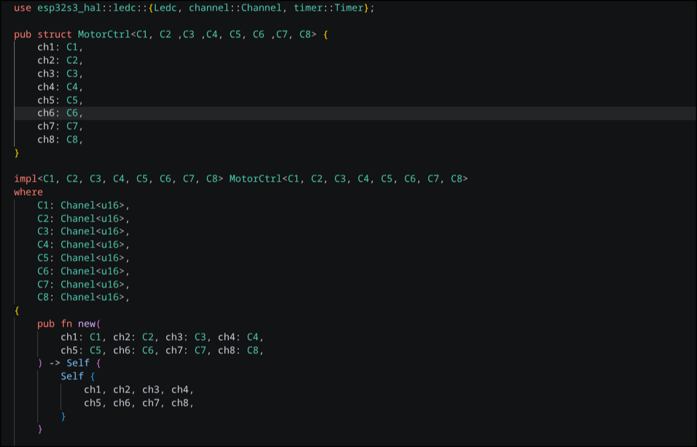
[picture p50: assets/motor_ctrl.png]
baka moment


how the hell can i make such a mistake literal spelling mistake ? 

ok fixed tht and main.rs architecture side done too now i will push and let deepseek debug and then mineself will debug the bugs tht will be generated by deepseek while debugging my bugs lol .

ok added firmware to readme done .

**Total time spent: 6 hours**

# Sept 10 : Starting with the remote 

At first lets start with creating the env* , for me as an arch user i just did sudo pacman -S rustup espup thts why i use arch btw its perfect ,

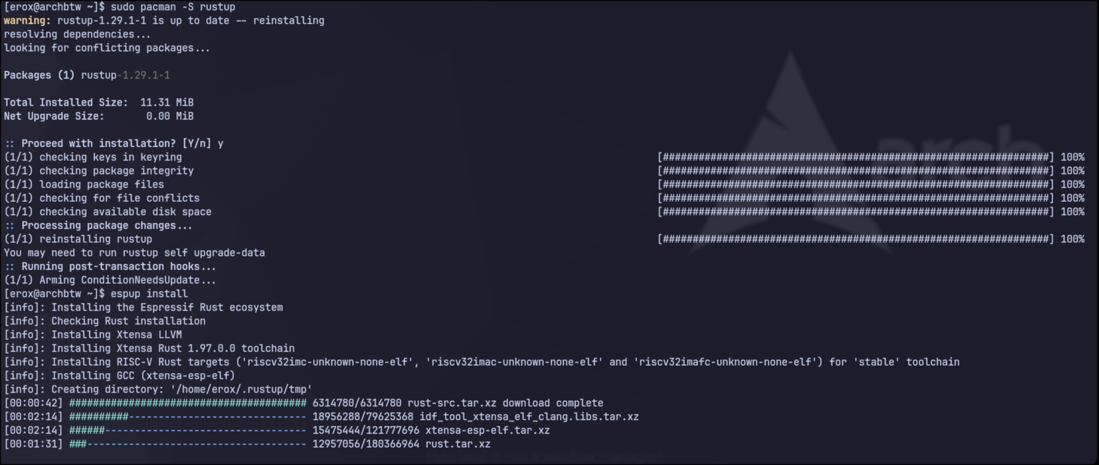
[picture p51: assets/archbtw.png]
i use arch btw


ok i just came to know my reference package api example was from a older esp hal HOLY .... now i need to migrate why it sucks on this level , i really dont wanna do it again . Luckily i didnt use the esp api's in filter and pid files , imma gonna let deepseek do this .

all settled it is migrated now so now i need to implant the esp-now logic , ok np . No way this time again i will use old reference code 

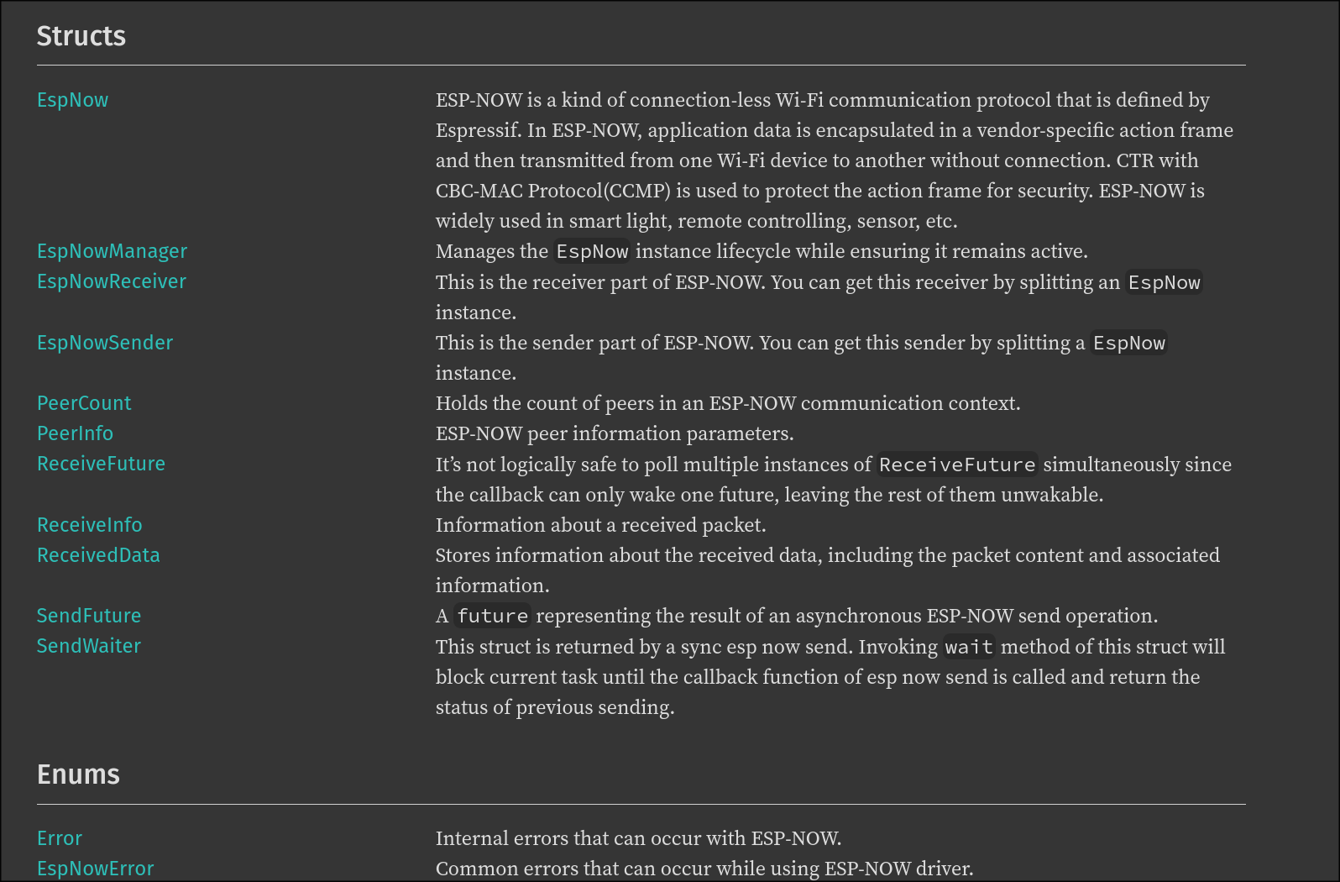
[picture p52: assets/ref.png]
ref structs


also i want to again say , crate is far better than pypi , "sometime truth hits hard " .  OK so imma gonna design the remote first easy peasy then the esp-now . i already have the required things in hand now , i mean i dont need to even buy a single thing(except a vero board and some headers to solder the esp i will buy it locally and by myself dont stress over orphy) so i thinks i shld build the remote first ok then if its decided then why not . My current esp(not the drone one but the one i have in home now ) is a esp32 devkitv1 likely wroom idk for sure but as i have it and 2 joysticks , i dont even need a pcb i will solder these to vero board and make it work . wait i found a old vero board too in my salavaged parts lets goooo!!

salavaged parts

so here i am goin to solder all of those on tht small vero board but idk where to mount the joysticks . ok mounted the joystics but my soldering is way too bad for this task . 
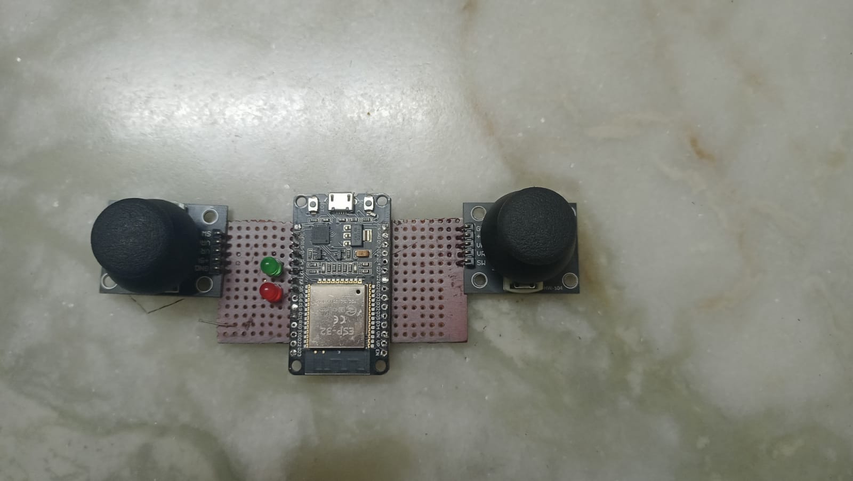
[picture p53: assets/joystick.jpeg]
joystick


nah i am out i will just make a pcb for it too or buy a diff iron , its too hard with this freaking iron i just cant even solder a led with it , i tried to re tin still it didnt work and after a lot of tests it exploded lol luckily i didnt got hurt but my remote is strucked now imma gonna do the software first or even just use wifi ahhh it sucks as hell still the final looks . 

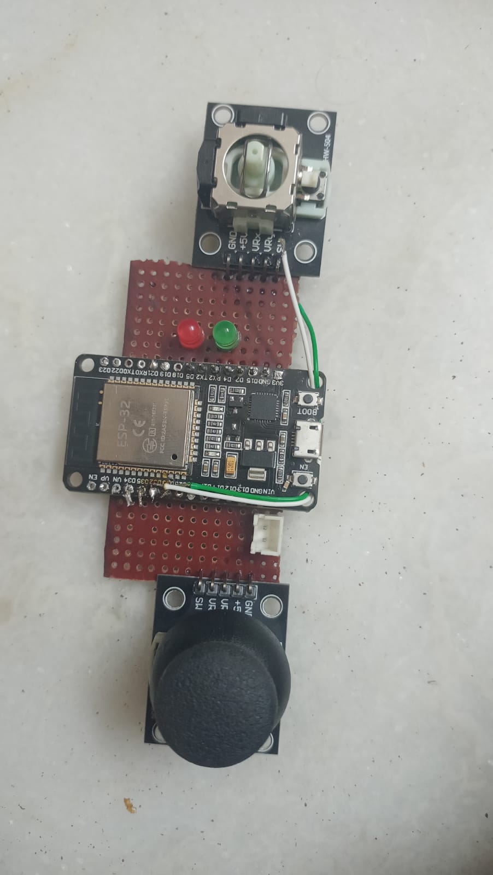
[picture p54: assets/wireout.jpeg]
it sucks


**Total time spent: 5 hours**

# Sept 11 : Remote's pcb

I have got a sick idea instead of a physical remote , i will just connect the esp to my phone via serial and use the esp with esp-now and my phone for controlling(as esp-now is 1Mx times better than just wifi ) ok so i am currently thinkin what shld i use a web ui or a kotlin app , its kinda hard for me to chose but anyways frontend = deepseek is cooking so i dont need to worry . Wait why am i not making a seperate pcb for the remote ? ok perfect for poc , phone but as idh much works so i will be designing the pcb too in parallel . 

 Ok started the schematics , i againn used the same module for esp , and tps again and built the schematic , heres it

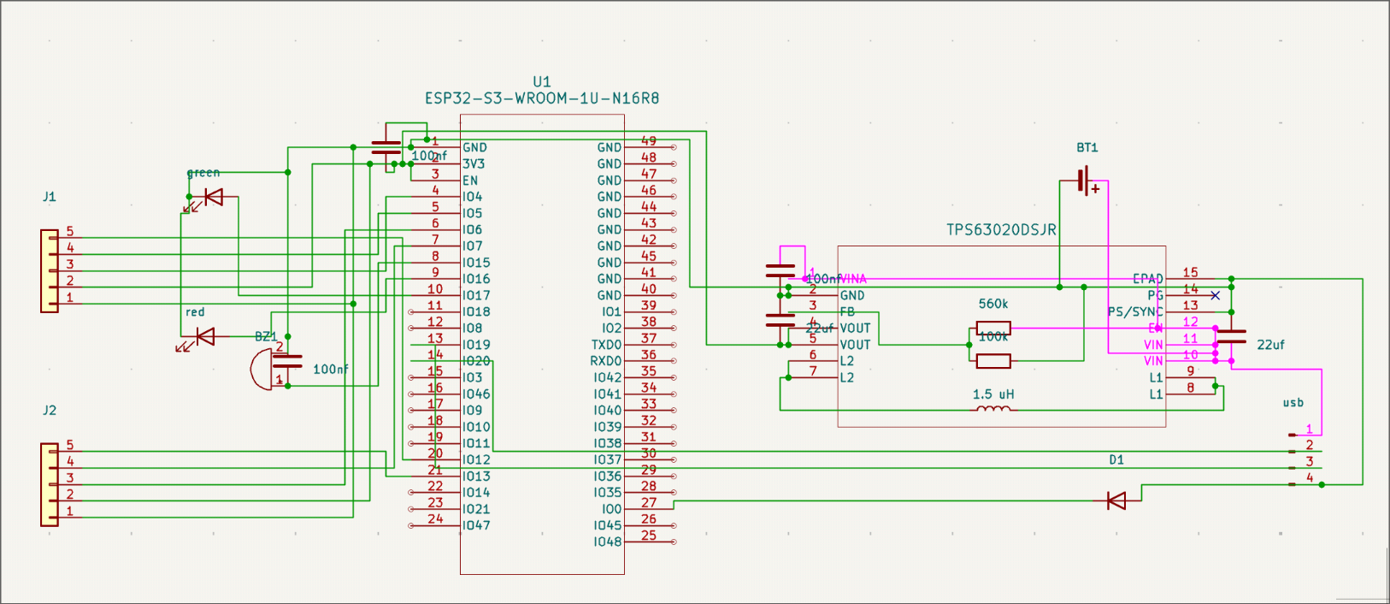
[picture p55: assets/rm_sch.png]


ok next is pcb . Ok pcb done too

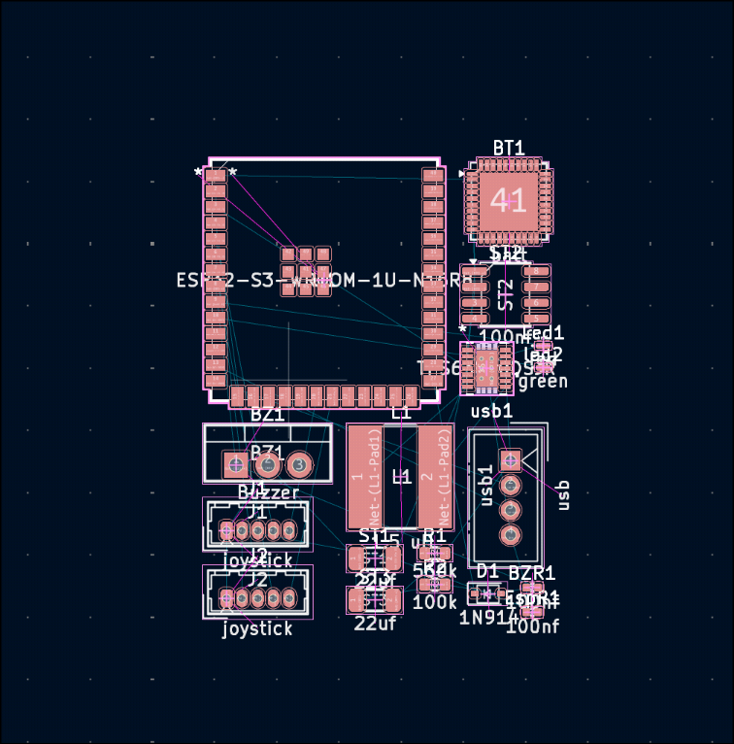
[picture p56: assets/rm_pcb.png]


wait why my 5v and 3.3v have same power rail??

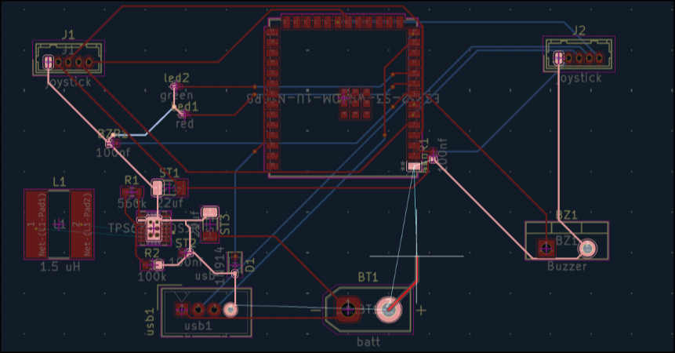
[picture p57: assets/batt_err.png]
prob


bruh it hella sucks wait when i highlighted i came to know its gnd shared not 5v wtf am i blind now?

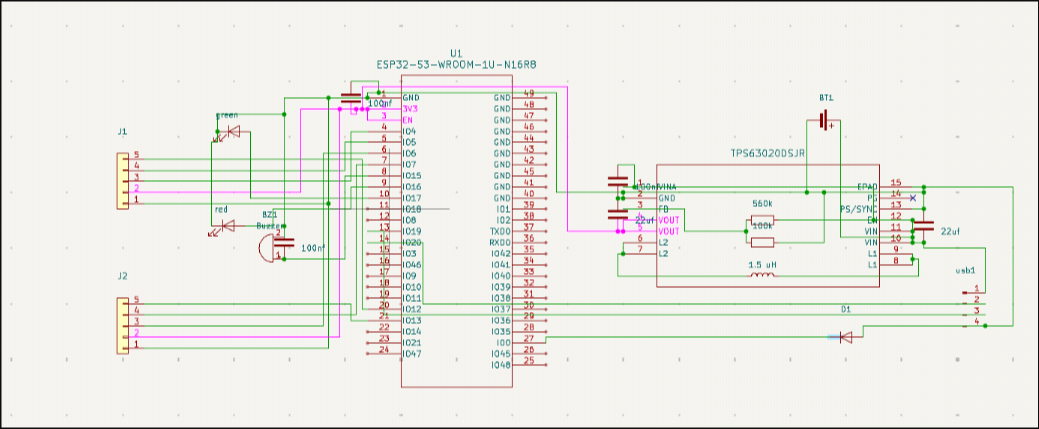
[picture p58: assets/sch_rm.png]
err


ok pcb done likely but i feel like i am forgeting something anyways take a look :

done

ohhhhh i get it what i forgot the mounting holes for the joysticks ok ok lemme add tht too

done

done finally the remote too , now i need to upgrade the bom but not only tht i wanna show ya guys a really funny thing 

lol

this is the 3d pic but lol my footprints are likr my buzzer is a 2 pin diode and my pins for the joystick looks hillarious .
ok today did a lot of heavy lifting now matane next day .

also now i tested it in jlcpcb take a look
jlcpcb

but theres a huge problem , the mpu6500 is out of stock same goes for mpy9250 so now i need to switch to mpu6050 , hell naw i will need to change my gerber , code and a lot of more things ahhh it sucks .Ok i found a alt in robu but it costs likely 8$ while the old one was barely 1.5$ nah not gonna waste this much money instead i will use a mpu6050 and redesign . ok so thts the task for tomorrow lemme upgrade the bom for now

**Total time spent: 6 hours**

# Sept 12 : Restart

The previous day , my reviewer told me my pcb is half cooked , but after watching a tutorial i came to know why he said it .
So this time i am goin to document it like a pro , heres the first schematics portion

restart

The esp , the tps , the bl5612's , the mpu every thing will be separated this time also according to the datasheet, the gpio19 and gpio20 are D+ and D-

data

next is connecting all the motor drivers with good enough pins .

done

done now i need to connect the mpu , as the breakout is always cheaper in india , why not ?

esp

i think i can just mount the mpu on top of the esp done  and a double tape will do the vibration avoidance thing .

schematic

This time i added a bmp180 too with the mpu6050 , also fixed the esp's en funcition by adding a 10k ohm res between 3.3v and en instead of the old direct connection .

after it , i added the caps needed on bl5612 ic's

caps_added

ok now i think imma gonna add the motors , thts easy .
Done already

motors_added

Now i think i have to add the caps on the tps and on the esp , on the mpu and bmp too . 

done i added a lots of caps this time , for the motors , for esp , for the mpu .....

caps

Now i need to add a button to en for reset i think a trace wd be just fine no button needed at all .

trace_addedd

ohh i actually wired the en cap wrong , it was on 3.3v instead of en , i fixed tht also changed the cap value to 10uf as idc if the delay is 100ms .

This time i ran drc , fixed some minor probs and added a battery , also 4 22uf caps in parallel :

final

Ok after it i added all the footprints , this one took me a lot of time really a lot of time 

footprint

Bruh wtf did i do wrong?? i got some big ic's instead of my poor resistors , lol needa fix tht 

lol

ok i fixed tht now lets dive into pcb wait maybe i shld save tht for tomorrow i already did a lot of work today !

fixeddd

**Total time spent: 8 hours**

# Sept 13 : Starin the pcb

pcb started

placed the bl5612's onto their right place now lets see what can my small raccon like brain do?

Bruh wtf i really placed another tps instead of my inductor , footprint is really hell .

fixed footprint

ok fixed it .

btw the barometer looks really big , needa fix its size .

done

done now i need to place everything on right place then seperate the ground ............and alll the tasks.

wait lemme resolv the 3d model first or i wont be able to mount the pcb . 

ok as shadow said , my own fcstd , done 

iusearchbtw
---
iusearchbtw 
---
iusearchbtw
---

done the model looks really sick
path is :
[path to model](./3d/lux.FCStd)

i took the old model as reference thts why it went this fast , still took me a bit time as i rebuild the geometry .

ok now the pcb , now finally its favorable as i have the model done but wait i forgot the mounting holes uhhh it sucks .

comps placed

placed all the components on their right position now i need a bit adjustment and then placement done

placement

looks like done but now some finishing ,
cropped

i cropped the pcb and fixed the placing looks like thts all before connection .

oh man the 3d model really ate all my time .

hm so i made filled zone for the gnd , and started routing 

motorsss

i added the thick af trace for it .

via

this time i made via's a lot more fat for more power draw . also connectd other things ,

usb

then i did the usb part , i used really small 0.1mm traces as d+ and d- doesnt carry much power, after tht i wired the tps to inductor , and more tht i forgot check the photo for it.

**Total time spent: 8 hours**

# Sept 14 : Finishing the pcb

today i wanna power the motors correctly :

pwr

done the right sided motors are fine now . phew!

pcb

this time i connected the usb c , the tps a bit more , and connected the resistors with the esp , its just some minor job . after a lil more connection it will be done . 

done

ok done the pcb looks cool
3d

heres the 3d model , it looks damn cool .

power

just take a look at the tps portion i made it tightly packed looks really cooool .

3dd

ahh i placed the mounting holes wrong now i need to replace them correctly ok lets do tht 

done

3d

wait but the edges are out of the frame needa fix tht eaxy job , cut the pcb baby.
no wait imma not gonna cut the pcb now , it will make me do a lot of things again.

jlc

lol the small via  pcb costs more than all the comps together , lol again .

so i need to make the via's bigger ah .

vias

fixed it uh now atleast it costs less than the comps .
jlcpcb

ok now i need to do the remote .

**Total time spent: 5.5 hours**

# Sept 15 : Remote schematics

i just realized i was wastin resources by allowcating a whole  esp32 s3 n16r8 to the remote , and i found esp32 c3 tht costs half the cost of the s3 and also as thts a breakout i am savin a lot of money too lol .
lol i cant find the footprint of esp32 c3 super mini , i tried gemini , gpt , google , no one was able to find it , looks like needa make it myself or make gpt make it for me haha buhhahhahhaha .

wait i found it , from reddit lol . but its footprint only no symbol i need symbol too so i think i might make the symbol myself . 

[the random reddit link](https://drive.google.com/file/d/1Ia2y5KgLuTCjiLleW4krdE9uNQLiYWtD/view)

now i will need to find or make the sym , wait its the s3 supermini not c3 super mini ahhhh life sucks ....

ok i will ditch the c3 supermini idea .. so what i am supposed to do now? maybe ditch the remote and controll with a phone? lol lets do tht ,nah ths not something like me to do , 
ok gah then imma gonna build with a esp module not breakout but tht costs too much for a basic thing , wait wait i can use my existing esp ah but tht one doesnt hav any external antenna , idk what to do now , i will just go with the c3 super mini thts good , i cant even do phone seria to my esp as my esp has uart instead of native esp like the s3 or c3 series . 

ohhhh i found gold take a look :

Peter's electric trick and electronic blog

oh i can do it to make my esp do the work already why worry ? 

wait even better ESP-M1 ESP8285 found a esp8266 and it is far cheaper imma gonna use it . wait its out of stock lol , maybe i shld go ahead and use my esp32-s3 as planned at first lol .  i checked Espressif ESP32-S3-MINI-1U-N8 Module but 
esp
it has lower sensivity so only option original route ahhhh i just wasted 5 hrs to save a few hundred rs and failed lol .

lol

ok thts enough i gotta sleep now or gonna die.

**Total time spent: 7 hours**

# Sept 16 :  

ok i started today with some research , looks like imma gonna reuse my joysticks and then but for tht i need a soldering but currently i only have a hot air station lol lets use tht 

sw

added switchs for the schematics  , now i think i shld design the pcb instead .

pcb

started the pcb 

done halfways

ah lol i did a lot of work still its no t even halfways done 

done

done finally i think now i can sleep in ease but wait idh any buzzer or led , let tht go just lets take it to jlcpcb i am realy sleepy .

wait arent the buttons too big??

and the vias are too small to manufacture , so i need to make them bigger , fixed them now need to rerun the drc 

drc

ran drc again , min dia size was err'ing so i changed all 

viasss

oh holy sh*t! now i need to fix it for the drone tooooo .

rt

this is the 3d, but i tried turning rt on , and lol my i5 1135g7 on zen 7.2.3 , got absolutely roasted af .

i will do the drones pcb and remotes cad tomorrow matane

**Total time spent: 7 hours**

# Sept 17 : cad for remote

lol lemme add the joystick footprint first , how can i forget tht ?

also i considered using a custom vtx but the costs lol , it crosses the 50$ as mine is t3 lol lets stic to the plan 

wow wow found a perfect antenna 

antenna

ts is 2.4ghz and dipole perfect , i read the dataset too its damn good. now need to fix the remote lol .
wait i need to remove the switchs to somewhere else as i need to use adc-1 on my esp for the nrx and nry of my joysticks as espnow shares a bit with the adc-2 lane
maybe? as it does wit wifi too !

joystck

done added the joystick support on the schematic now need to add joystick on pcb too.

led

added led too , but findin it and the resistors were a really boarin task still did it and found the cheapest one as usual .

res

added a led for the c type usb too and as its 5v i used 2x 220 ohm res on serial as on bulk its cheaper , 330ohm might give me more brightness but why waste money?

done

done finally now i need the .step for the joysticks

grabcad

grabcad is the best i found the model in just a minute .

added the 3d model for the joystick

lol

lol mounted on the wrong direction lemme fix tht .

joystick

done but wait i didnt do the free cad thing today at all , ahhh ok gonna do tomorrow lemme export the pcb .step first 

done!

sch

it looooks tooo odd , the schematic led portion but like i care , it works , it is documented , it is separated and tagged thts all i care abt lol 

**Total time spent: 5 hours**

# Sept 18 : 

jy

i placed th joystick wrong needa rotate tht .

done

fixed it  lol . it was problamatic.

switch

added the joystick switch connection to sch now next is pcb .

don

added to pcb too , now lets make the case for the remote

i expanded the pcb , and tried to adjust atleast one screw hole for the joystick and this is my 5th attempt lol

screw screw

still cant do tht maybe the 7th time, thts my lucky number ,



lol its the 13th time still got only one screw on right place ,

finally

finally now both are on right places uf.

remote

thts how it looks i added the screws and not it looks good enough but the switchs are too small to even reach the surface of the cad ima gonna make .
anyways it means lets start with the cad , no i dont wanna it sucks ahhh but i need to do tht anyways lol .

made the gerber and exported the step now next is cad .....

started

started now need to make another sketch and rm the pcb body volume 

cadd

thts how it looks not i think i will go with minimal cover on the topside .

ohh holy sht i forgot the usb c anyways gonna do tht tomorrow .

**Total time spent: 4.5 hours**

# Sept 19:

ok i just saw my joysticks arent alligned AHHHHHHHH , wtf and i did a bit work in the cad , it sucks as hell now i will need to redo it , ok lets fix tht atleast.

done

this time i wont do tht err again .

fian

finally it looks symetric now !

antenna

after reading the datasheet , made a hole for the antenna , perfect size right?

pocket

perfect position to make a hole lol , i made the hole for usb c too now need to add a pad to cover the other side hole too !

filled

ok filled the hole on the other side , now need to rm the extra fillin .

done

now just need to make the upper cover for the remote and done easy peasy 

remote

doesnt look tht cool but if it works , it works .

done

now its comepletely done , added bosses to screw the pcb in too , now its done , just need to tune the hole for the pcb with the joystick a bit and done , easy lol

fixed

fixed the screw mountin prob so am i done ? already?



so this is the final look of the the remote , now gonna export stl .

**Total time spent: 3 hours**

# Sept 20 : Today we're codin 

at first i changed the names frm mpu6500 to mpu6050 in the code , also the WHO_AM_I resister value frm the configureable 0x70 and 0x73 in mpu6500 to 0x68 in mpu6050 , oh man readin datasheets sucks . i am not gonna touch any other resisters anyways , even it doesnt even exist on mpu6050 , why clean tht up . Maybe i use a mpu6500 on v2 ? thts why i wont remove them . 

Mizuketa another change , the temps values 

done

now wht shld i change ? ohhh the api's of the whole code lol forgot them all . 
done thts all for today i am sleepy

**Total time spent: 0.5 hours**

# Sept 21 : Found a major bug 

today i looked at the pcb AND I FOUND A SEVERE BUG , i didnt connect the correct power pins , i mean 
pcb_err

see this ,the gnd and gnd1 are separated as intended but the 5v and 5va are separated too thts a prob needa fix tht , i think i need diodes only thts enough lol

thx god , i examined the pcb with a lot of time instead of just submittin it .

ok now its getting complex the gpio0 portion , i thought i wd just use a diode between 3.3v and gnd BUT I AM USING ONLY 1 TPS so the 3.3v will be powered if usb plugged , so OHHHHHH I have a perfect solution , usb power , get lost , i can just use battery to power the mcu all the time and the usb will only do d+ and d- , am i not a freakin genious?

AH but now idh the usb power detector lol

Oh i can use the d+ as a detector i mean i can use a nand gate and done hell yeah 

oh wait i can just use the usb's 5v why disturb my d+ , wait wait if its the case why dont i just use my current architecture but use the battery's 5va and use tht as the battery power and gnd is when usb plugged?

ah lol , lemme change tht section

tps

fixed the tps portion now need to do same with the esp .No wait ,now the 3.3v is permanent , even worse , i cant use this now 

fool

so i cant use my utterly fool design , hm .

LOL i just read the datasheet again and it said , GPIO0 is pulled high default but if some brat wanna pull it up with e res , no prob lol.

i just never needed tht thing ahhhhhh .

maybe i will add a led for the usb connection . but nah not now , i am already tired readin datasheets for a hour.

fixed

now needa fix the pcb .

gnd1

ohh hell , its such a mess 

fixed

fixed this mess a lot uf.

finally

finally routed everything now just need to export the gerbers again uf .

ok done now i can push and sleep finally .

**Total time spent: 2.5 hours**

# Sept 22 :

As i thought the remote also has the same prob lol

lol

now needa fix tht , so again if i do this , the remote will be battery mandetory but idh any place for battery on the case , maybe i will add one small battery and mount it somewhere like under the remote , not a prob . 

Holy shit , my laptop got shut down in mid and gave me casps  specific err , like youre dead . i was scared and teared down the whole laptop down , and recovered it now the "s" button is acting odd and touchpad not workin ahhhhhhhh tht s is jusst getting everywhere ahhh . ok back to work . 

How the hell can i work with this piece of shit , S is just gettin spammed .

i cant even use kicad in peace ahhhh , i thought after fixing the pcb , i wd supgrasde the readme but its not possible . 

ok fixed it but with the cost of my steak of 18 days and a external keyboard ah .

so wht shld i do now? ok enough today i basically did nothin . 

**Total time spent: 1 hours**

# Sept 23 : 

Ok now i am goin to fix tht err

done

done , fixed the power prob now imma gonna reexamine it.

also for my led , i mean the usb led , it is powered by batter , i mean no battery , no usb led lol ok good easter egg not gonna fix it .

done

done now i think the remote is ready i can just export it . 

done

ok now lets check the drone's schematic AGAIN .

wait i just realized , i used diff gnd and diff live for the led on remote lol .

wait my kicad definately have somekind of prob , it isnt saving as it did .

fixed

ok so i finally fixed this utterly disgraceful piece of sht so now i needa export again and we are ready to go .

done

so now i think i will go for the readme now , then ship it .

ok so readme now .
    
README.md done

**Total time spent: 4 hours**

# Sept 24 : 

Today i will add the final imgs 









ok looks like its good already now i can just hope for the reviewer to give it an approve .

**Total time spent: 0.5 hours**

# Sept 30 :

yo , finally got review'd , it was rejected though but fine , lemme fix the probs , he said to organize the readme :

okk done i js saw a cool ref and tried tht now my readme is fine too , also adjusted the pcb a bit so the silkscreen doesnt go out of board , idk if there is anyother issue. also fixed the bom inside the readme .

done :



also added pcb manufecturing portion 



this one looks cheap because the coupon is there 

uf fixed the boms too 

rest is upto reviewer !!

**Total time spent: 1 hours**

# Oct 9 :

the reviewer indeed took a lot of time but now ik the final flaws once its fixed , its fixed

added screws to connect the body and the lid 


---


now after it i added 3d model to the pcb for esp and now gonna make pin diagrams as the reviewer said i need tht too ,
i think imma gonna use inkscape .

its too odd i am not used to this thing , the time has come , my fault for getting involved with generic things while i  am the krita guy .

hell naw its too hard even on krita , maybe i shld use a auto backgroud remover tool 

fck off , why making a diagram so hard , i didnt lapse it or it wd be nearly more than 2 hrs js to make a diagram , okk done finally now i can push 



looks good enough right ? 

ok done anyways , i used gpt at first to diffuse the diagram atleas 10 times but  it made tht even worse at last i went neuclear and made the whole thing myself now rest is js to organise the readme a bit and done hell yeah

**Total time spent: 2.5 hours**

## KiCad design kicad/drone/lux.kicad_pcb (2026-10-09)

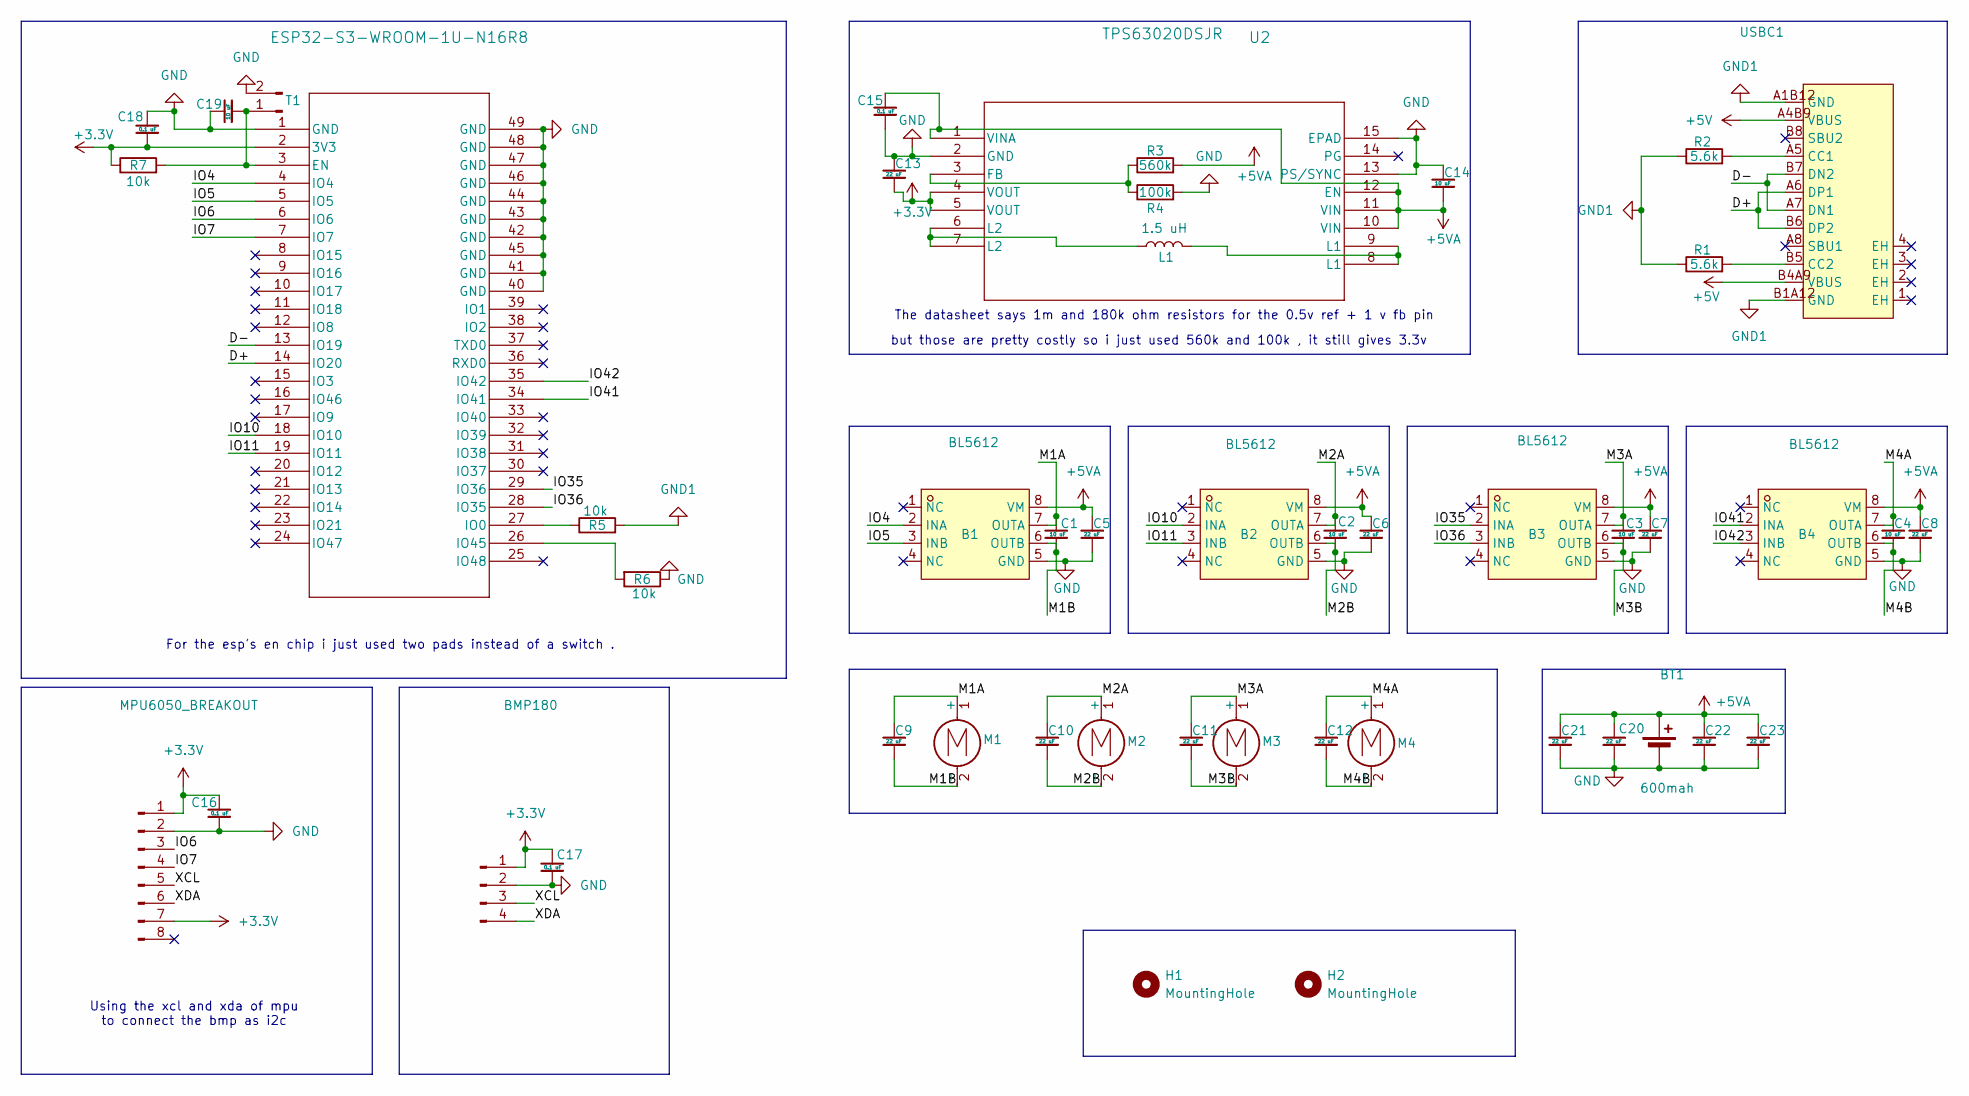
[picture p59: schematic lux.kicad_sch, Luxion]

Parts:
B1, B2, B3, B4: BL5612; SOP-8_L4.9-W3.9-P1.27-LS6.0-BL; MPN BL5612; LCSC Part C2841019
BMP1: BMP180; Hirose_DF13-04P-1.25DSA_1x04_P1.25mm_Vertical
BT1: 600mah; PinHeader_1x02_P2.54mm_Vertical
C1, C2, C3, C4, C14, C19: 10 uF; C_0805_2012Metric
C5, C6, C7, C8, C9, C10, C11, C12, C13, C20, C21, C22, C23: 22 uF; C_1206_3216Metric
C15, C16, C17, C18: 0.1 uF; C_0402_1005Metric
H1, H2: MountingHole; MountingHole_2.5mm
L1: 1.5 uH; L_Bourns-SRN8040_8x8.15mm
M1, M2, M3, M4: Motor_DC; JST_PH_B2B-PH-K_1x02_P2.00mm_Vertical
MPU1: MPU6050_BREAKOUT; Hirose_DF13-08P-1.25DSA_1x08_P1.25mm_Vertical
R1, R2: 5.6k; R_0603_1608Metric
R3: 560k; R_0603_1608Metric
R4: 100k; R_0603_1608Metric
R5, R6, R7: 10k; R_0603_1608Metric
T1: trace; C_1206_3216Metric
U1: ESP32-S3-WROOM-1U-N16R8; ESP32-S3-WROOM-1U_EXP
U2: TPS63020DSJR; DSJ14_2P85X1P58
USBC1: TYPE-C-31-M-12; USB-C_SMD-TYPE-C-31-M-12_1; MPN TYPE-C-31-M-12; LCSC Part C165948

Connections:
+3.3V: BMP1.1, C13.2, C16.1, C17.1, C18.2, MPU1.1, MPU1.7, R7.1, U1.2 (3V3), U2.4 (VOUT), U2.5 (VOUT)
+5V: USBC1.A4B9 (VBUS), USBC1.B4A9 (VBUS)
+5VA: B1.8 (VM), B2.8 (VM), B3.8 (VM), B4.8 (VM), BT1.1 (+), C5.1, C6.1, C7.1, C8.1, C14.2, C15.1, C20.1, C21.1, C22.1, C23.1, R3.2, U2.1 (VINA), U2.10 (VIN), U2.11 (VIN), U2.12 (EN)
/D+: U1.14 (IO20), USBC1.A6 (DP1), USBC1.B6 (DP2)
/D-: U1.13 (IO19), USBC1.A7 (DN1), USBC1.B7 (DN2)
/IO4: B1.2 (INA), U1.4 (IO4)
/IO5: B1.3 (INB), U1.5 (IO5)
/IO6: MPU1.3, U1.6 (IO6)
/IO7: MPU1.4, U1.7 (IO7)
/IO10: B2.2 (INA), U1.18 (IO10)
/IO11: B2.3 (INB), U1.19 (IO11)
/IO35: B3.2 (INA), U1.29 (IO36)
/IO36: B3.3 (INB), U1.28 (IO35)
/IO41: B4.2 (INA), U1.34 (IO41)
/IO42: B4.3 (INB), U1.35 (IO42)
/M1A: B1.7 (OUTA), C1.1, C9.1, M1.1 (+)
/M1B: B1.6 (OUTB), C1.2, C9.2, M1.2 (-)
/M2A: B2.7 (OUTA), C2.1, C10.1, M2.1 (+)
/M2B: B2.6 (OUTB), C2.2, C10.2, M2.2 (-)
/M3A: B3.7 (OUTA), C3.1, C11.1, M3.1 (+)
/M3B: B3.6 (OUTB), C3.2, C11.2, M3.2 (-)
/M4A: B4.7 (OUTA), C4.1, C12.1, M4.1 (+)
/M4B: B4.6 (OUTB), C4.2, C12.2, M4.2 (-)
/XCL: BMP1.3, MPU1.5
/XDA: BMP1.4, MPU1.6
GND: B1.5 (GND), B2.5 (GND), B3.5 (GND), B4.5 (GND), BMP1.2, BT1.2 (-), C5.2, C6.2, C7.2, C8.2, C13.1, C14.1, C15.2, C16.2, C17.2, C18.1, C19.1, C20.2, C21.2, C22.2, C23.2, MPU1.2, R4.2, R6.1, T1.2, U1.1 (GND), U1.40 (GND), U1.41 (GND), U1.42 (GND), U1.43 (GND), U1.44 (GND), U1.45 (GND), U1.46 (GND), U1.47 (GND), U1.48 (GND), U1.49 (GND), U2.2 (GND), U2.13 (PS/SYNC), U2.15 (EPAD)
GND1: R1.1, R2.1, R5.2, USBC1.A1B12 (GND), USBC1.B1A12 (GND)
unnamed: L1.1, U2.6 (L2), U2.7 (L2)
unnamed: L1.2, U2.8 (L1), U2.9 (L1)
unnamed: C19.2, R7.2, T1.1, U1.3 (EN)
unnamed: R5.1, U1.27 (IO0)
unnamed: R6.2, U1.26 (IO45)
unnamed: R3.1, R4.1, U2.3 (FB)
unnamed: R2.2, USBC1.A5 (CC1)
unnamed: R1.2, USBC1.B5 (CC2)

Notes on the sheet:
The datasheet says 1m and 180k ohm resistors for the 0.5v ref + 1 v fb pin
Using the xcl and xda of mpu to connect the bmp as i2c
For the esp's en chip i just used two pads instead of a switch .
but those are pretty costly so i just used 560k and 100k , it still gives 3.3v

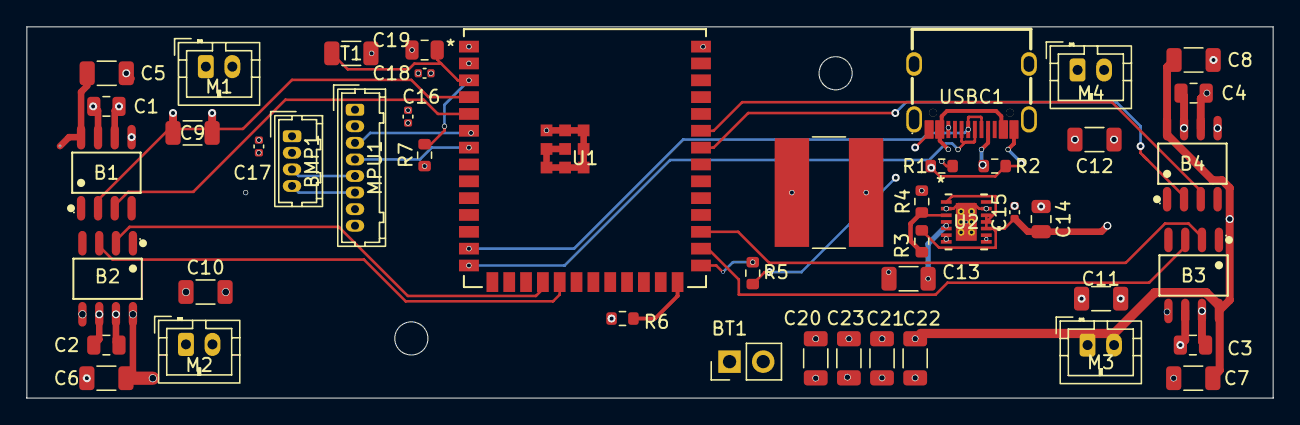
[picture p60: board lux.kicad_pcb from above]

Board: 4 copper layers, 94.0 x 28.0 mm, 50 parts (0 on the bottom side), 35 nets.

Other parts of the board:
H1#2, H2#2: MountingHole; MountingHole_2.5mm

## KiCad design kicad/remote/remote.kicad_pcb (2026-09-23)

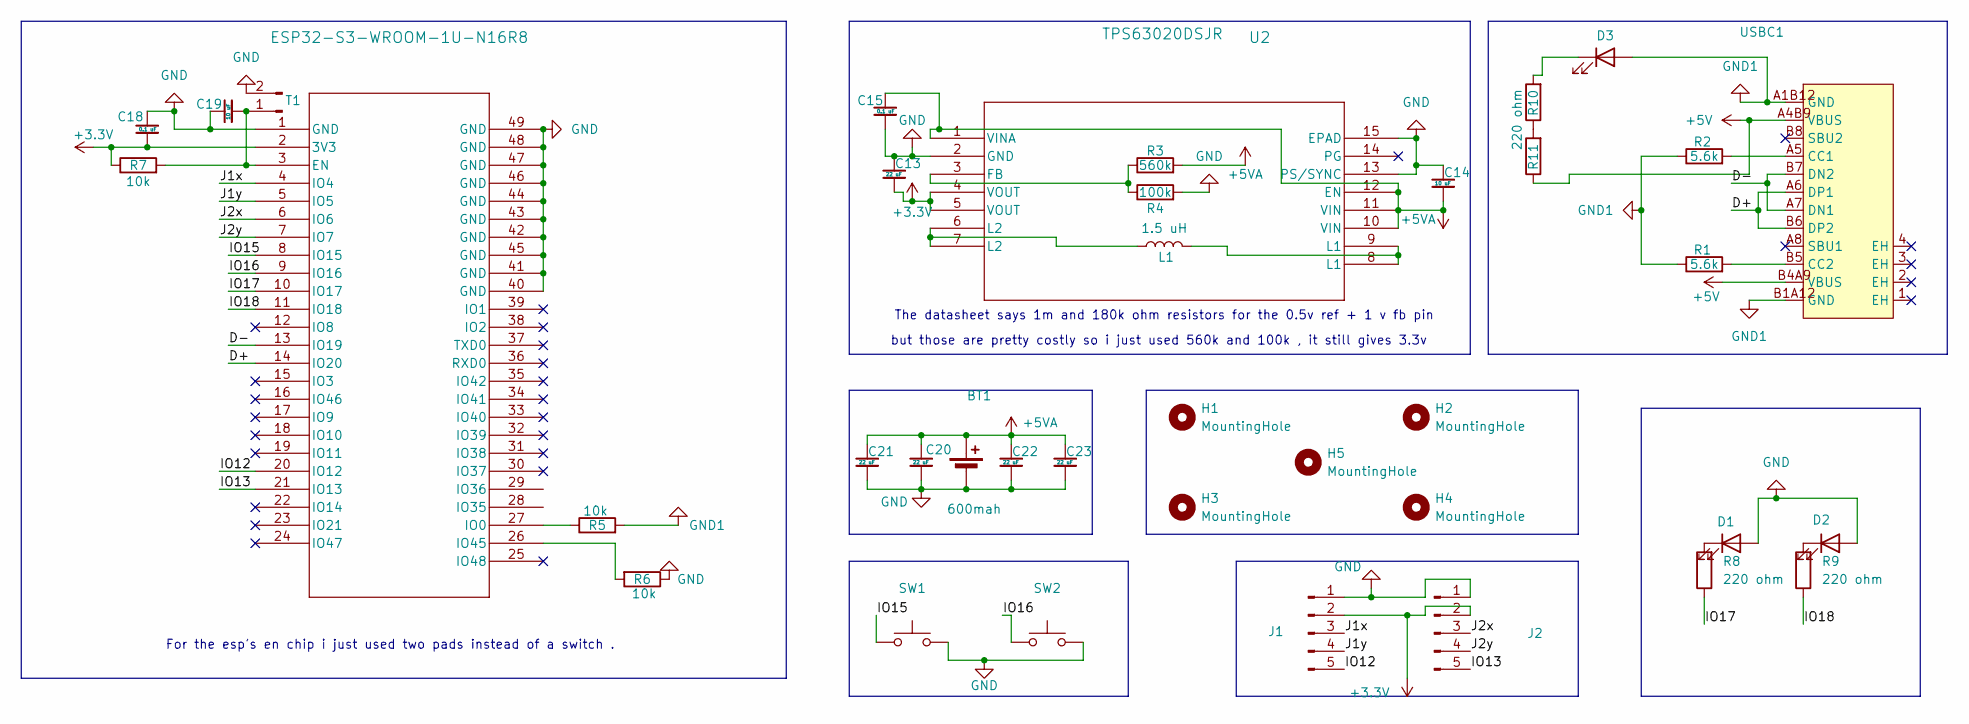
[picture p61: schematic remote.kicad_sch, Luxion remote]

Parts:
BT1: 600mah; PinHeader_1x02_P2.54mm_Vertical
C13, C20, C21, C22, C23: 22 uF; C_1206_3216Metric
C14, C19: 10 uF; C_0805_2012Metric
C15, C18: 0.1 uF; C_0402_1005Metric
D1, D3: Yellow; LED_1206_3216Metric
D2: WHITE; LED_1206_3216Metric
H1, H2, H3, H4, H5: MountingHole; MountingHole_2.5mm
J1, J2: joystick; PinHeader_1x05_P2.54mm_Vertical
L1: 1.5 uH; L_Bourns-SRN8040_8x8.15mm
R1, R2: 5.6k; R_0603_1608Metric
R3: 560k; R_0603_1608Metric
R4: 100k; R_0603_1608Metric
R5, R6, R7: 10k; R_0603_1608Metric
R8, R9, R10, R11: 220 ohm; R_0603_1608Metric
SW1, SW2: sw; SW_PUSH_6mm_H5mm
T1: trace; C_1206_3216Metric
U1: ESP32-S3-WROOM-1U-N16R8; ESP32-S3-WROOM-1U_EXP
U2: TPS63020DSJR; DSJ14_2P85X1P58
USBC1: TYPE-C-31-M-12; USB-C_SMD-TYPE-C-31-M-12_1; MPN TYPE-C-31-M-12; LCSC Part C165948

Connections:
+3.3V: C13.2, C18.2, J1.2, J2.2, R7.1, U1.2 (3V3), U2.4 (VOUT), U2.5 (VOUT)
+5V: R11.1, USBC1.A4B9 (VBUS), USBC1.B4A9 (VBUS)
+5VA: BT1.1 (+), C14.2, C15.1, C20.1, C21.1, C22.1, C23.1, R3.2, U2.1 (VINA), U2.10 (VIN), U2.11 (VIN), U2.12 (EN)
/D+: U1.14 (IO20), USBC1.A6 (DP1), USBC1.B6 (DP2)
/D-: U1.13 (IO19), USBC1.A7 (DN1), USBC1.B7 (DN2)
/IO12: J1.5, U1.20 (IO12)
/IO13: J2.5, U1.21 (IO13)
/IO15: SW1.1, U1.8 (IO15)
/IO16: SW2.1, U1.9 (IO16)
/IO17: R8.1, U1.10 (IO17)
/IO18: R9.1, U1.11 (IO18)
/J1x: J1.3, U1.4 (IO4)
/J1y: J1.4, U1.5 (IO5)
/J2x: J2.3, U1.6 (IO6)
/J2y: J2.4, U1.7 (IO7)
GND: BT1.2 (-), C13.1, C14.1, C15.2, C18.1, C19.1, C20.2, C21.2, C22.2, C23.2, D1.2 (A), D2.2 (A), J1.1, J2.1, R4.2, R6.1, SW1.2, SW2.2, T1.2, U1.1 (GND), U1.40 (GND), U1.41 (GND), U1.42 (GND), U1.43 (GND), U1.44 (GND), U1.45 (GND), U1.46 (GND), U1.47 (GND), U1.48 (GND), U1.49 (GND), U2.2 (GND), U2.13 (PS/SYNC), U2.15 (EPAD)
GND1: D3.2 (A), R1.1, R2.1, R5.2, USBC1.A1B12 (GND), USBC1.B1A12 (GND)
unnamed: D1.1 (K), R8.2
unnamed: D2.1 (K), R9.2
unnamed: D3.1 (K), R10.2
unnamed: L1.1, U2.6 (L2), U2.7 (L2)
unnamed: L1.2, U2.8 (L1), U2.9 (L1)
unnamed: R10.1, R11.2
unnamed: C19.2, R7.2, T1.1, U1.3 (EN)
unnamed: R5.1, U1.27 (IO0)
unnamed: R6.2, U1.26 (IO45)
unnamed: R3.1, R4.1, U2.3 (FB)
unnamed: R2.2, USBC1.A5 (CC1)
unnamed: R1.2, USBC1.B5 (CC2)

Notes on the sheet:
The datasheet says 1m and 180k ohm resistors for the 0.5v ref + 1 v fb pin
For the esp's en chip i just used two pads instead of a switch .
but those are pretty costly so i just used 560k and 100k , it still gives 3.3v

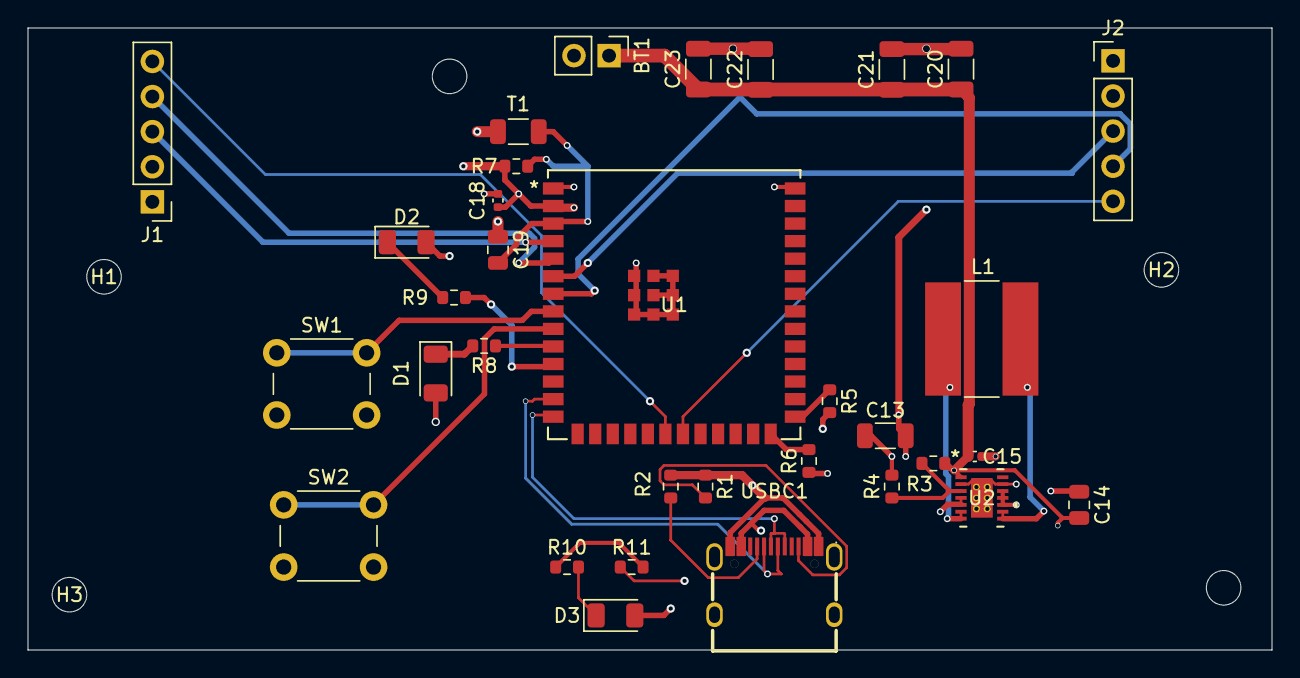
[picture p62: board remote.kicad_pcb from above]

Board: 4 copper layers, 90.0 x 45.0 mm, 38 parts (0 on the bottom side), 29 nets.

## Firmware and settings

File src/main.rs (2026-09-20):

#![no_std]
#![no_main]

use esp_hal::{
    clock::CpuClock,
    gpio::{Input, Output},
    ledc::{
        channel::{self, ChannelIFace},
        timer::{self, TimerIFace},
        LSGlobalClkSource, Ledc, LowSpeed,
    },
    main,
    spi::{
        master::{Config as SpiConfig, Spi},
        Mode,
    },
    time::Rate,
};

use esp_println::println;
use esp_backtrace as _;

mod mpu;
mod pid;
mod motor;
mod filter;

use mpu::Mpu6050;
use motor::MotorCtrl;
use filter::ComFil;
use pid::Pidctrl;

#[main]
fn main() -> ! {
    let config = esp_hal::Config::default().with_cpu_clock(CpuClock::max());
    let peripherals = esp_hal::init(config);

    let io = esp_hal::gpio::Io::new(peripherals.GPIO, peripherals.IO_MUX);

    let m1_ina = Output::new(io.pins.gpio4, esp_hal::gpio::Level::Low);
    let m1_inb = Output::new(io.pins.gpio5, esp_hal::gpio::Level::Low);
    let m2_ina = Output::new(io.pins.gpio6, esp_hal::gpio::Level::Low);
    let m2_inb = Output::new(io.pins.gpio7, esp_hal::gpio::Level::Low);
    let m3_ina = Output::new(io.pins.gpio15, esp_hal::gpio::Level::Low);
    let m3_inb = Output::new(io.pins.gpio16, esp_hal::gpio::Level::Low);
    let m4_ina = Output::new(io.pins.gpio17, esp_hal::gpio::Level::Low);
    let m4_inb = Output::new(io.pins.gpio18, esp_hal::gpio::Level::Low);

    let cs = Output::new(io.pins.gpio10, esp_hal::gpio::Level::High);
    let sck = Output::new(io.pins.gpio12, esp_hal::gpio::Level::Low);
    let mosi = Output::new(io.pins.gpio11, esp_hal::gpio::Level::Low);
    let miso = Input::new(io.pins.gpio13);
    let _int = Input::new(io.pins.gpio46);

    let spi = Spi::new(
        peripherals.SPI2,
        SpiConfig::default()
            .with_frequency(Rate::from_mhz(1))
            .with_mode(Mode::_0),
    )
    .unwrap()
    .with_sck(sck)
    .with_mosi(mosi)
    .with_miso(miso)
    .with_cs(cs);

    let mut ledc = Ledc::new(peripherals.LEDC);
    ledc.set_global_slow_clock(LSGlobalClkSource::APBClk);

    let mut lstimer0 = ledc.timer::<LowSpeed>(timer::Number::Timer0);
    lstimer0
        .configure(timer::config::Config {
            duty: timer::config::Duty::Duty10Bit,
            clock_source: timer::LSClockSource::APBClk,
            frequency: Rate::from_khz(20),
        })
        .unwrap();

    let channel0 = ledc.channel(channel::Number::Channel0, m1_ina);
    let channel1 = ledc.channel(channel::Number::Channel1, m1_inb);
    let channel2 = ledc.channel(channel::Number::Channel2, m2_ina);
    let channel3 = ledc.channel(channel::Number::Channel3, m2_inb);
    let channel4 = ledc.channel(channel::Number::Channel4, m3_ina);
    let channel5 = ledc.channel(channel::Number::Channel5, m3_inb);
    let channel6 = ledc.channel(channel::Number::Channel6, m4_ina);
    let channel7 = ledc.channel(channel::Number::Channel7, m4_inb);

    let mut motor_ctrl = MotorCtrl::new(
        channel0, channel1, channel2, channel3,
        channel4, channel5, channel6, channel7,
    );

    let mut mpu = match Mpu6050::new(spi, cs) {
        Ok(mpu) => {
            println!("imu init'ed");
            mpu
        }
        Err(e) => {
            loop {
                motor_ctrl.stop_all();
            }
        }
    };

    let mut roll = Pidctrl::new(1.0, 0.0, 0.0);
    let mut pitch = Pidctrl::new(1.0, 0.0, 0.0);
    let mut yaw = Pidctrl::new(1.0, 0.0, 0.0);

    let mut filter = ComFil::new(0.98);
    let mut throttle = 0.0;
    let mut target_roll = 0.0;
    let mut target_pitch = 0.0;
    let mut target_yaw = 0.0;
    let mut armed = false;

    let loop_delay = 10;
    let dt = loop_delay as f32 / 1000.0;

    println!("fly");

    loop {
        match mpu.read_data() {
            Ok(data) => {
                let attitude = filter.update(
                    data.accel_x,
                    data.accel_y,
                    data.accel_z,
                    data.gyro_x,
                    data.gyro_y,
                    data.gyro_z,
                    dt,
                );

                let roll_output = roll.calculate(target_roll, attitude.roll);
                let pitch_output = pitch.calculate(target_pitch, attitude.pitch);
                let yaw_output = yaw.calculate(target_yaw, attitude.yaw);

                if armed && throttle > 0.05 {
                    let motor_speeds =
                        mix_motors(throttle, roll_output, pitch_output, yaw_output);

                    motor_ctrl.set_motor(0, motor_speeds[0], true);
                    motor_ctrl.set_motor(1, motor_speeds[1], false);
                    motor_ctrl.set_motor(2, motor_speeds[2], false);
                    motor_ctrl.set_motor(3, motor_speeds[3], true);
                } else {
                    motor_ctrl.stop_all();
                }

                println!(
                    "R:{:.2} P:{:.2} Y:{:.2} | T:{:.2}",
                    attitude.roll,
                    attitude.pitch,
                    attitude.yaw,
                    throttle
                );
            }

            Err(e) => {
                println!("imu read error , {:?}", e);
                motor_ctrl.stop_all();
            }
        }
    }
}

pub fn mix_motors(
    throttle: f32,
    roll: f32,
    pitch: f32,
    yaw: f32,
) -> [u16; 4] {
    let m1 = (throttle - pitch + roll + yaw).clamp(0.0, 1.0) * 1000.0;
    let m2 = (throttle + pitch + roll - yaw).clamp(0.0, 1.0) * 1000.0;
    let m3 = (throttle + pitch - roll + yaw).clamp(0.0, 1.0) * 1000.0;
    let m4 = (throttle - pitch - roll - yaw).clamp(0.0, 1.0) * 1000.0;

    [m1 as u16, m2 as u16, m3 as u16, m4 as u16]
}

enum Command {
    Arm,
    Disarm,
    Throttle(f32),
    SetTarget(f32, f32, f32),
}

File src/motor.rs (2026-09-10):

use esp32s3_hal::ledc::{
    channel::{Channel, ChannelIFace},
    timer::Timer,
    Ledc,
};

pub struct MotorCtrl<C1, C2, C3, C4, C5, C6, C7, C8> {
    ch1: C1,
    ch2: C2,
    ch3: C3,
    ch4: C4,
    ch5: C5,
    ch6: C6,
    ch7: C7,
    ch8: C8,
}

impl<C1, C2, C3, C4, C5, C6, C7, C8> MotorCtrl<C1, C2, C3, C4, C5, C6, C7, C8>
where
    C1: ChannelIFace<'static, esp32s3_hal::ledc::LowSpeed>,
    C2: ChannelIFace<'static, esp32s3_hal::ledc::LowSpeed>,
    C3: ChannelIFace<'static, esp32s3_hal::ledc::LowSpeed>,
    C4: ChannelIFace<'static, esp32s3_hal::ledc::LowSpeed>,
    C5: ChannelIFace<'static, esp32s3_hal::ledc::LowSpeed>,
    C6: ChannelIFace<'static, esp32s3_hal::ledc::LowSpeed>,
    C7: ChannelIFace<'static, esp32s3_hal::ledc::LowSpeed>,
    C8: ChannelIFace<'static, esp32s3_hal::ledc::LowSpeed>,
{
    pub fn new(
        ch1: C1,
        ch2: C2,
        ch3: C3,
        ch4: C4,
        ch5: C5,
        ch6: C6,
        ch7: C7,
        ch8: C8,
    ) -> Self {
        Self {
            ch1,
            ch2,
            ch3,
            ch4,
            ch5,
            ch6,
            ch7,
            ch8,
        }
    }

    pub fn set_motor(&mut self, motor: u8, speed: u16, cw: bool) {
        let speed = speed.min(1000);
        let (ina, inb) = match motor {
            0 => (&mut self.ch1, &mut self.ch2),
            1 => (&mut self.ch3, &mut self.ch4),
            2 => (&mut self.ch5, &mut self.ch6),
            3 => (&mut self.ch7, &mut self.ch8),
            _ => return,
        };

        let duty = (speed as u32 * 255 / 1000) as u8;

        if cw {
            let _ = ina.set_duty(duty);
            let _ = inb.set_duty(0);
        } else {
            let _ = ina.set_duty(0);
            let _ = inb.set_duty(duty);
        }
    }

    pub fn stop_all(&mut self) {
        let _ = self.ch1.set_duty(0);
        let _ = self.ch2.set_duty(0);
        let _ = self.ch3.set_duty(0);
        let _ = self.ch4.set_duty(0);
        let _ = self.ch5.set_duty(0);
        let _ = self.ch6.set_duty(0);
        let _ = self.ch7.set_duty(0);
        let _ = self.ch8.set_duty(0);
    }
}

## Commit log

2026-09-04 1st day
    [8250_Frame_v7.stl, lux.kicad_pcb]
2026-09-06 holy 11 hrs
    [8250_Frame_v7.stl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]
2026-09-06 bom added
2026-09-06 lets see if it renders
    [8250_Frame_v7.stl]
2026-09-08 pid added finally
2026-09-09 motors done too
2026-09-09 mpu driver done
2026-09-09 ah motor driver prob fixed , mpu polished
    [motor.rs, mpu.rs]
2026-09-11 sept 11
    [lux.kicad_pcb, lux.kicad_sch, remote.kicad_pcb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]
2026-09-11 ahh life sucks
    [lux-B_Cu.gbr, lux-B_Mask.gbr, lux-B_Paste.gbr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]
2026-09-12 sept 12
    [lux.kicad_pcb, lux.kicad_sch, lux.step]
2026-09-13 sept 13
    [lux.FCStd, lux.kicad_pcb, lux.kicad_sch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]
2026-09-14 sept 14
    [lux-B_Mask.gbr, lux-B_Paste.gbr, lux-B_Silkscreen.gbr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]
2026-09-16 sept 16
    [.kicad_sch, lux.kicad_pcb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]
2026-09-17 sept 17
    [remote.kicad_pcb, remote.kicad_sch, remote.step]
2026-09-18 sep 18
    [remote-B_Cu.gbr, remote-B_Mask.gbr, remote-B_Paste.gbr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]
2026-09-19 sept 19
    [remote.FCStd, remote.kicad_pcb, remote.step]
2026-09-19 lol forgot to add the 3mf
    [remote.3mf]
2026-09-21 sept 21
    [lux-B_Cu.gbr, lux-B_Mask.gbr, lux-B_Paste.gbr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]
2026-09-23 sept 22 lol
    [lux.kicad_pcb, remote.kicad_pcb]
2026-09-23 readme more
    [.kicad_sch, lux.kicad_pcb, lux.step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]
2026-09-23 bom done
    [BOM.csv]
2026-09-23 better pharsing for github
    [BOM.csv]
2026-09-30 bom upgraded
2026-10-01 organized a bit
    [lux.kicad_pcb, lux.kicad_sch, remote-Body.3mf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]
2026-10-01 upgraded the bom
    [BOM.csv]
2026-10-09 done jolly
    [lux.kicad_pcb, remote-Body.3mf, remote-lid.3mf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]
